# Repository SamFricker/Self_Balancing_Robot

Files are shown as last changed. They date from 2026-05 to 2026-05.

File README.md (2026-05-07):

# Self-Balancing Robot (PID Controlled)

A two-wheeled self-balancing robot using stepper motors, an IMU, and a PID control system.

## CAD Model
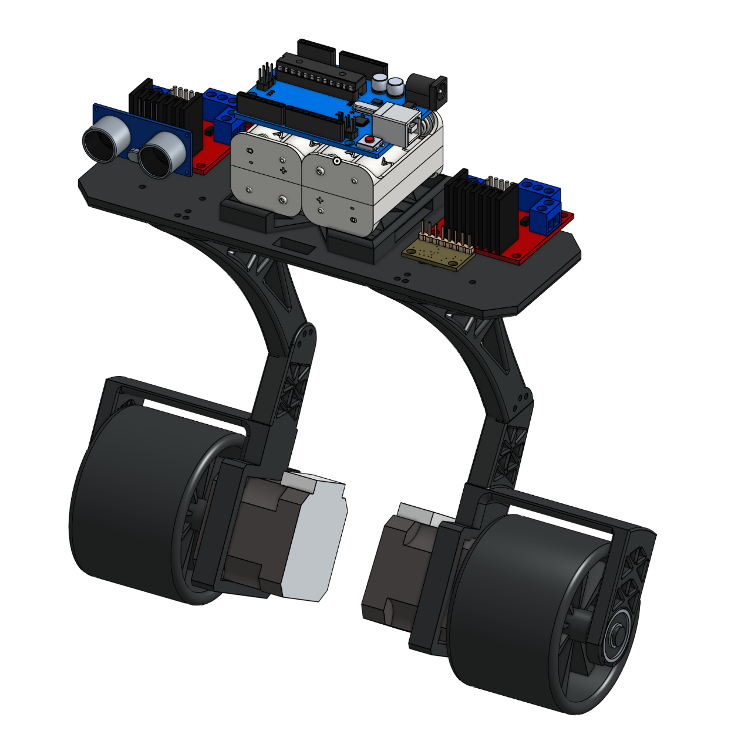
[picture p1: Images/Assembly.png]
Final CAD Design:


## Final Build
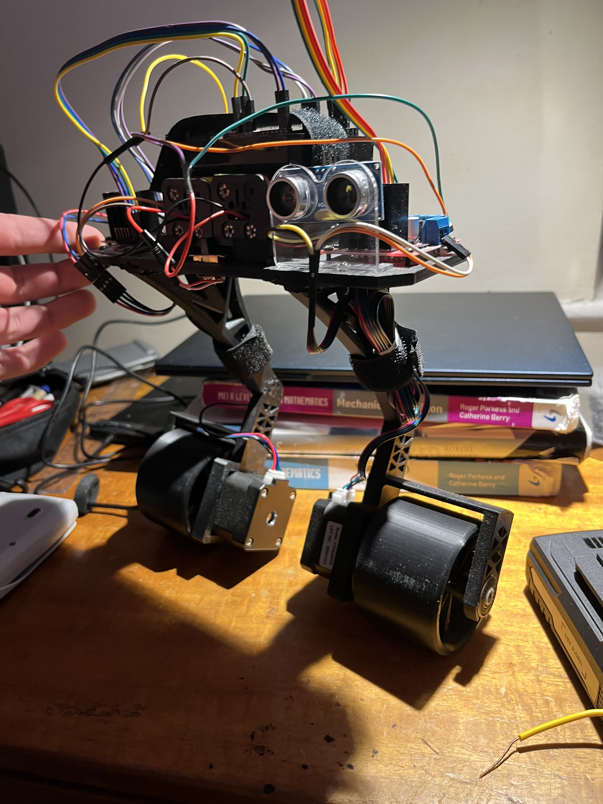
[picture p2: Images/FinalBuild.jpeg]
Final Build:


## Links
[Onshape CAD](https://cad.onshape.com/documents/77841446f1b41ab34413a012/w/3976edb733c54040d0cf4a11/e/2c77be59104294cb53648c13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)

[Google Slides](https://docs.google.com/presentation/d/11a6YWDmIo3_uVGVUQJ4fRdrg8UfdcLoaTxgzl_Zd4M4/edit?usp=sharing)

### All rough workings documented on google slides

## Overview
This project investigates real-time control systems by building a Segway-style robot that balances using a PID feedback loop. The aim of this project was to gain familiarity with PID controllers and the manufacturing processes needed to create a final working device.

## Key Features
- PID control
PID equation
- Complementary filter (IMU fusion)
Complimentary filter equation
- Stepper motor drive
- Custom 3D printed chassis
- Kill switch

## Repository Structure
- docs/ (theory + design)
- hardware/ (CAD + electronics)
- software/ (Arduino + PC code)
- experiments/ (tuning + logs)

## Status
Work in progress, There is movement, PID controller needs tuning and motor drivers need replacing.

## Current Reflections and Next Steps
Overall the project has acheived its aims. The design and build processes were very successful due to manufacturing considerations taken in CAD allowing for components to be mounted on easily. Additionally, the programming stage has deppened my understanding of PID controllers which was the main goal.

The project had some challenges which act as a learning opportunity for future robotics projects. namely, the heated inserts were too small so plastic welding was used, low quality motor drivers caused jittering so adopting microstepping to smooth motion, and the power source having a low current limit and causing motors to stall, this was fixed by repurposing an 18V electric strimmer battery, 3D printing a press-fit mount and wiring a fixed resistor to work safely with the BMS (battery management system). With some more fixes to the circuitry the project would be fully complete. Main goals have still been acheived and funding has been redirected to other projects at the moment, planning to revisit this soon.

Future updates will include, ultrasound sensor implemetation for obstacle detection and HC-05 blutooth module transmission between a laptop and the arduino to offload the computing power and allow for more software features.

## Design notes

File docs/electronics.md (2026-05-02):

# Electronics

## Circuit for individual Motor
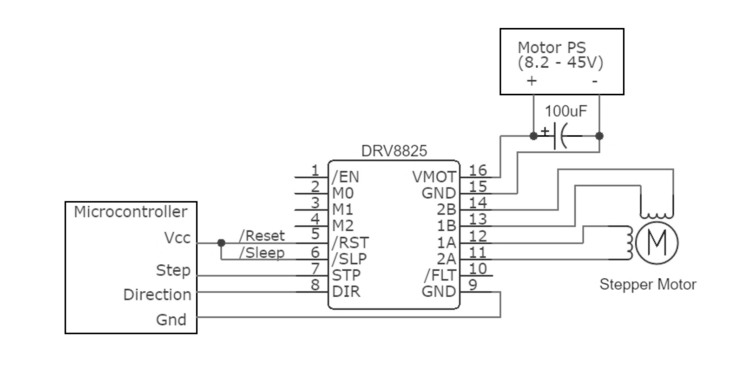
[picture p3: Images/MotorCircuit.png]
Circuit for individual Motor


## Components
- Arduino Uno
- MPU6050 IMU (6 DOF)
- NEMA 17 stepper motors
- DRV8825 motor drivers
- NMGT18-Li_48 2.0Ah 18V rechargable battery pack

## Problems
- Insufficient current supply
- Driver overheating

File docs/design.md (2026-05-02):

# Mechanical Design

## Dimensions
Approx 20cm x 30cm

## Mass
~1.66kg total

## Shape
The robot uses angled legs with triangular holes to reduce weight and material cost
We want the robot to be relatively tall as this will make it easier to balance, yet not so tall that it could be balanced by a human as this is the task we want to automate.

## Issues
- Wheel misalignment → vibration
- Weak axle
- Loose electronics mounting

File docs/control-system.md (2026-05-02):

# Control System

The robot uses a PID controller:
PID equation

The core idea is that the proportional term grows with error (adjusting motors toward desired point), The integral term grows with accumulated error (adjusting motors such that error is not large for a long time), and the derivative term changes with the rate of error (making sure the motor doesnt overshoot)
## Strategy
1. Balance loop (angle → motor speed)
2. Velocity compensation (reduces drift)

## Notes
- Highly sensitive to tuning
- Noise affects derivative term

## To do
- the robot need properly tuning, establishing a P controler first then we can tune values accordingly to get smooth motion.

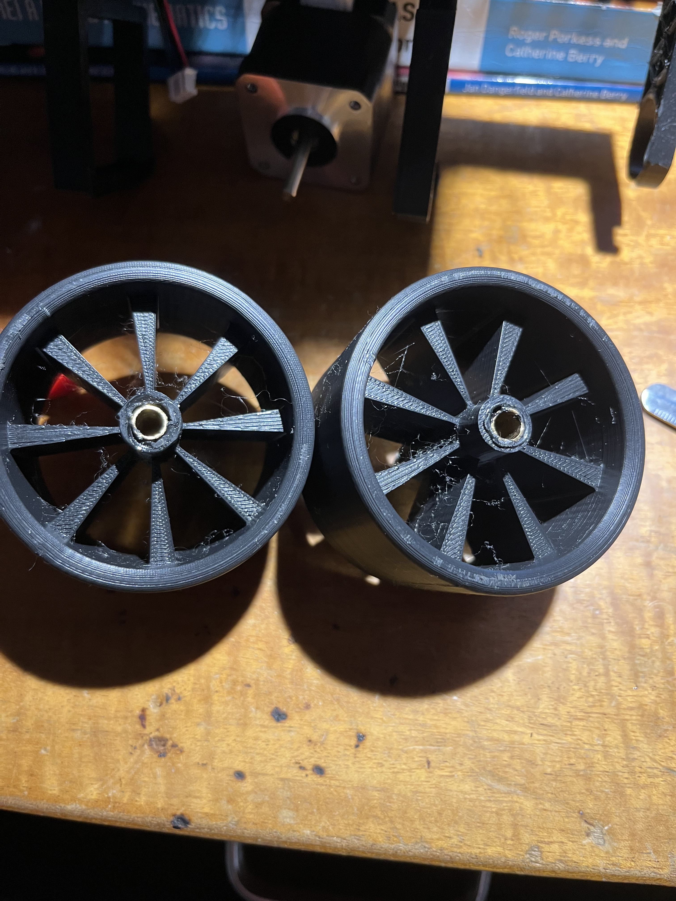
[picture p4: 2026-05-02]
Images/Wheels.jpeg

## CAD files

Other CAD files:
CAD/Assembly.stl

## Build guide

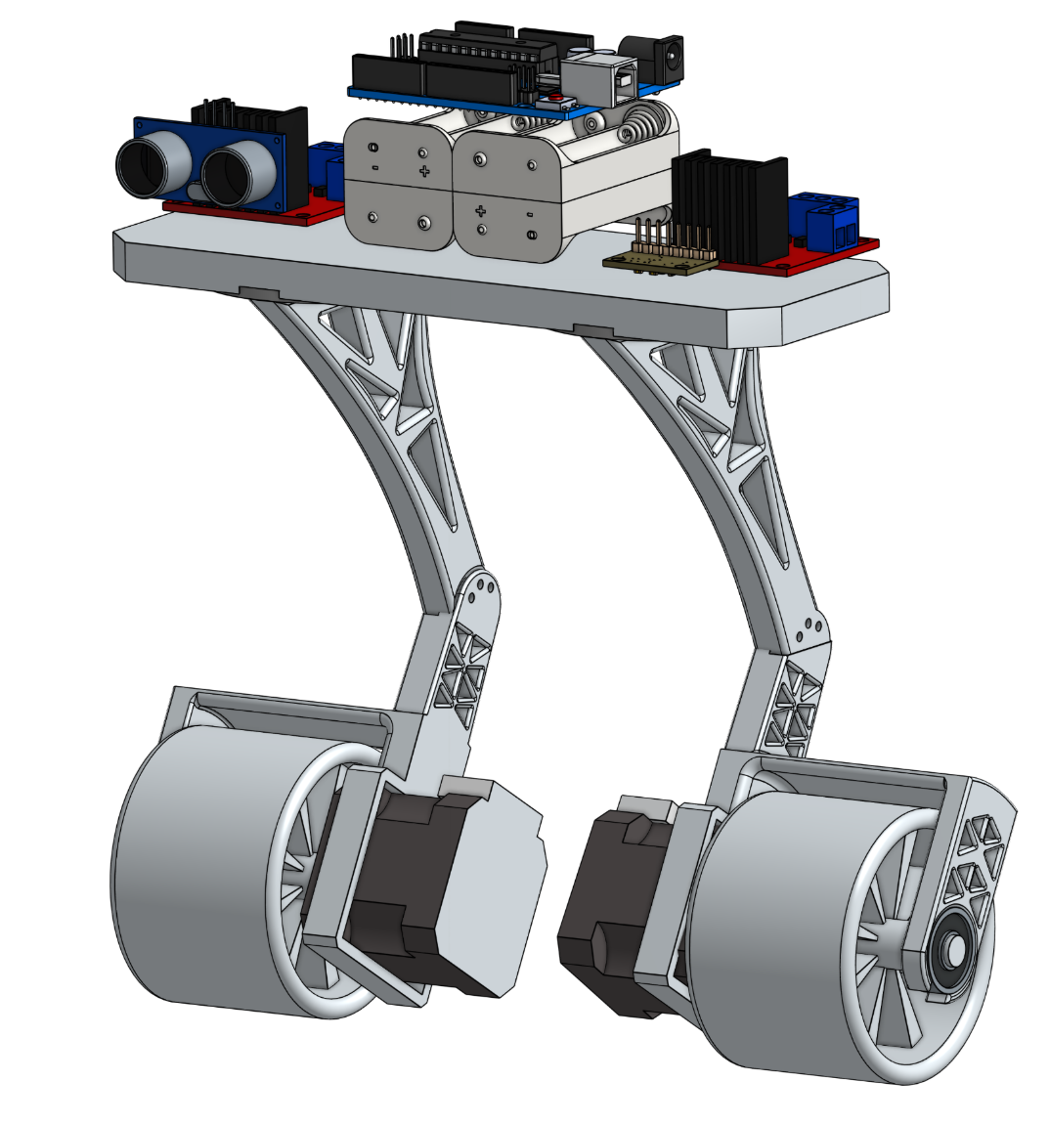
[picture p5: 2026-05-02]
Images/Assembly_white.png

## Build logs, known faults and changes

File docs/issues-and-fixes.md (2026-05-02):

# Issues and Fixes

## Hardware Issues
- Motor stalling → fix: higher current battery
- Driver overheating → replace drivers

## Software Issues
- Timing inconsistency → move PID onboard
- Serial delay → reduce dependency on PC

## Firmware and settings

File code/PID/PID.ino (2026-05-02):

// Include necessary libraries
#include <Wire.h>
#include <MPU6050.h>
#include <Stepper.h>

#define PI_OVER_180 0.0174533  // Precompute pi/180

float alpha = 0.95; // Complementary filter weight variable

// set intial pitch and time to zero
float pitch = 0; // zero is a placeholder value whilst we dont have IMU data
unsigned long prev_time = 0;

// Set limits for stepper motors
const int maxSpeed = 100;  // rps
const int stepsPerRevolution = 200;

// Initialise stepper motor pin layout and imu
Stepper left(stepsPerRevolution, 8, 9, 10, 11);
Stepper right(stepsPerRevolution, 2, 3, 4, 5);
MPU6050 imu;

// begin serial monitor and start timer
void setup() {
  Serial.begin(9600);
  Wire.begin();
  imu.initialize();
  prev_time = millis();
}

// start main operating loop
void loop() {

  // on every loop, get the current time and calculate the time difference of the last loop dt.
  unsigned long curr_time = millis();
  float dt = (curr_time - prev_time) * 0.001; // in ms
  prev_time = curr_time;

  // Get IMU data
  int16_t ax, ay, az, gx, gy, gz;
  imu.getMotion6(&ax, &ay, &az, &gx, &gy, &gz);

  // --- COMPLEMENTARY FILTER ---

  // calculate the accelerometer pitch value and the anguular velocity in the pitch direction
  float accPitch = -atan2(ax, az);
  float omegaY = gy * 0.007633; // use the given conversion factor from IMU manufacturers datasheet

  // Calculate the pitch angle using complementary filter
  pitch = (alpha * (pitch + omegaY * dt * PI_OVER_180) + (1 - alpha) * accPitch);

  //int pitchDEG = abs((pitch * 57.2958) - 3);

  // --- PITCH PID CONTROLLER ---

  // Set constants
  float Kp = 17, Ki = 3, Kd = 10; // chosen randomly, to be determined experimentally
  float maxPID = 1500, targetPitch = 0;
  float intTerm = 0, previousPitch = 0;

  // calculate error in pitch angle
  float error = targetPitch - pitch;

  // calculate integral and derivative terms iteratively
  intTerm += error * dt;
  float drvTerm = (previousPitch - pitch) / dt;
  previousPitch = pitch;

  // Calculate PID value
  float PID = (Kp * error) + (Ki * intTerm) + (Kd * drvTerm);

  // Limit PID to its maximum value
  if (PID > maxPID){
    PID = maxPID;
  } else if(PID < -maxPID){
    PID = -maxPID;
  }

  // Serial.print("PID = "); // Sanity check
  // Serial.println(PID);

  // Set threshold PID value for motors to prevent vibrations and jittering
  if (PID > 50 || PID < -50){
    right.setSpeed(abs(PID));
    left.setSpeed(abs(PID));
  }

  // set the step count to 5 (steps per loop)
  int stepCount = 5;

  // set direction of the motors
  if(PID != 0){
    if (PID > 0) {
      right.step(-stepCount);
      left.step(-stepCount);
    } else if (PID < 0) {
      right.step(stepCount);
      left.step(stepCount);
    }
  }
}
